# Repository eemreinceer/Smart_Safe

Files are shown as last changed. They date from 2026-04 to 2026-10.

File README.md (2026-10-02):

# SmartSafe

ESP32-CAM based RFID access-control and IoT safe prototype.

SmartSafe combines embedded firmware, a physical RFID authorization path, a solenoid-lock driver, event capture, Firebase Realtime Database synchronization, a web dashboard, KiCad PCB sources and Fusion 360 mechanical files.

## What this project demonstrates

- C++ firmware on ESP32-CAM with FreeRTOS tasks and a non-blocking state-machine design.
- Local RFID allowlist authorization using an RC522 reader.
- Fail-closed handling for missing credentials, missing TLS CA data and unprovisioned OTA authentication.
- Solenoid/MOSFET lock-control path with explicit actuator-command state.
- Firebase RTDB event synchronization with an offline queue.
- Append-only event logging and role-separated database rules for device/admin/operator access.
- PlatformIO build and mock-test workflow with GitHub Actions checks.
- KiCad schematic/PCB sources and Fusion 360 enclosure/mechanical sources.

## Architecture

~~~text
RFID allowlist
      |
      v
ESP32-CAM firmware ---> MOSFET / solenoid lock
      |                         |
      |                         +--> commanded lock state
      v
Firebase RTDB <--------- device status and audit events
      ^
      |
Authorized dashboard ---> alarm command request
~~~

The physical RFID decision is local to the device. The cloud and web dashboard do not directly unlock the safe.

## Repository map

- FIRMWARE/Platform.IO/ - ESP32-CAM firmware, mocks and PlatformIO configuration
- FIRMWARE/WEB/akilli-kasa-dashboard/ - dashboard, Firebase config template and RTDB rules
- PCB/ - KiCad schematic and PCB sources
- 3D/ - Fusion 360 source files
- docs/ - physical bring-up and acceptance checklist
- SECURITY.md - security assumptions and reporting guidance

## Local configuration

Secrets are intentionally excluded from Git. Copy the templates locally:

~~~bash
cd FIRMWARE/Platform.IO
cp include/secrets.example.h include/secrets.h

cd ../WEB/akilli-kasa-dashboard/web
cp firebase-config.example.js firebase-config.js
~~~

Do not commit Wi-Fi credentials, Firebase service-account keys, device passwords, OTA secrets, tokens or personal event images. Use separate Firebase identities for the device and dashboard, and deploy the RTDB rules before connecting a real device.

## Build and test

~~~bash
cd FIRMWARE/Platform.IO
pio run -e esp32cam
pio run -e esp32cam-hardware
pio run -e esp32cam-production
./wokwi_test.sh
~~~

The Wokwi/mock path checks firmware behavior and RFID flows; it is not proof of physical lock safety, cloud availability or hardware electrical correctness. Follow the physical bring-up checklist before energizing a real actuator.

## Security boundaries

- RC522 UID matching is not cryptographic authentication and cards can be cloned.
- is_locked represents the commanded actuator state because the prototype has no physical lock-position sensor.
- A solenoid must use an appropriate external supply, common ground and flyback protection.
- ESP32-CAM and RC522 logic are 3.3 V; signal levels and MOSFET gate drive must be verified against the relevant datasheets.
- This is a prototype and must not be treated as the sole security layer for valuable assets.

## Project scope

This is a personal engineering and learning project. It includes AI-assisted development in parts; the repository documents the implemented architecture, security decisions, test paths and limitations rather than claiming production readiness.

## License

No LICENSE file has been added yet. Reuse and redistribution should not be assumed until a license is explicitly added.

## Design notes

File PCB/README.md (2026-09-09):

# PCB kaynakları

`akilli_guvenlik_kasasi/` altındaki KiCad proje, şema ve PCB dosyaları tasarım
kaynağıdır.

Repository'deki eski Gerber, drill, zip ve schematic PDF dosyaları güncel RFID +
MOSFET mimarisini temsil etmedikleri için kaldırılmıştır. PCB tasarımı
tamamlanıp ERC/DRC kontrolleri geçmeden bu repository'den üretim dosyası
gönderilmemelidir.

Yeni üretim paketi oluşturulurken en az şu dosyalar aynı KiCad revizyonundan
yeniden üretilmelidir:

- Copper, solder mask ve silkscreen Gerber katmanları
- Edge cuts
- PTH ve NPTH drill dosyaları
- Gerber job dosyası
- Assembly/BOM dokümanları
- Görsel kontrol için schematic PDF

KiCad'in kullanıcıya ve yerel pencere durumuna özel `*.kicad_prl` dosyaları
takip edilmez.

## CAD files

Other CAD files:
3D/DFPLAYER.f3d
3D/ESP-32_CAM.f3d
3D/LM2596 VOLTAGE REGULATOR.f3d
3D/PCB.f3z
3D/SOLENOID LOCK.f3d
3D/akilli_guvenlik_kasasi_pcb_v1.f3z

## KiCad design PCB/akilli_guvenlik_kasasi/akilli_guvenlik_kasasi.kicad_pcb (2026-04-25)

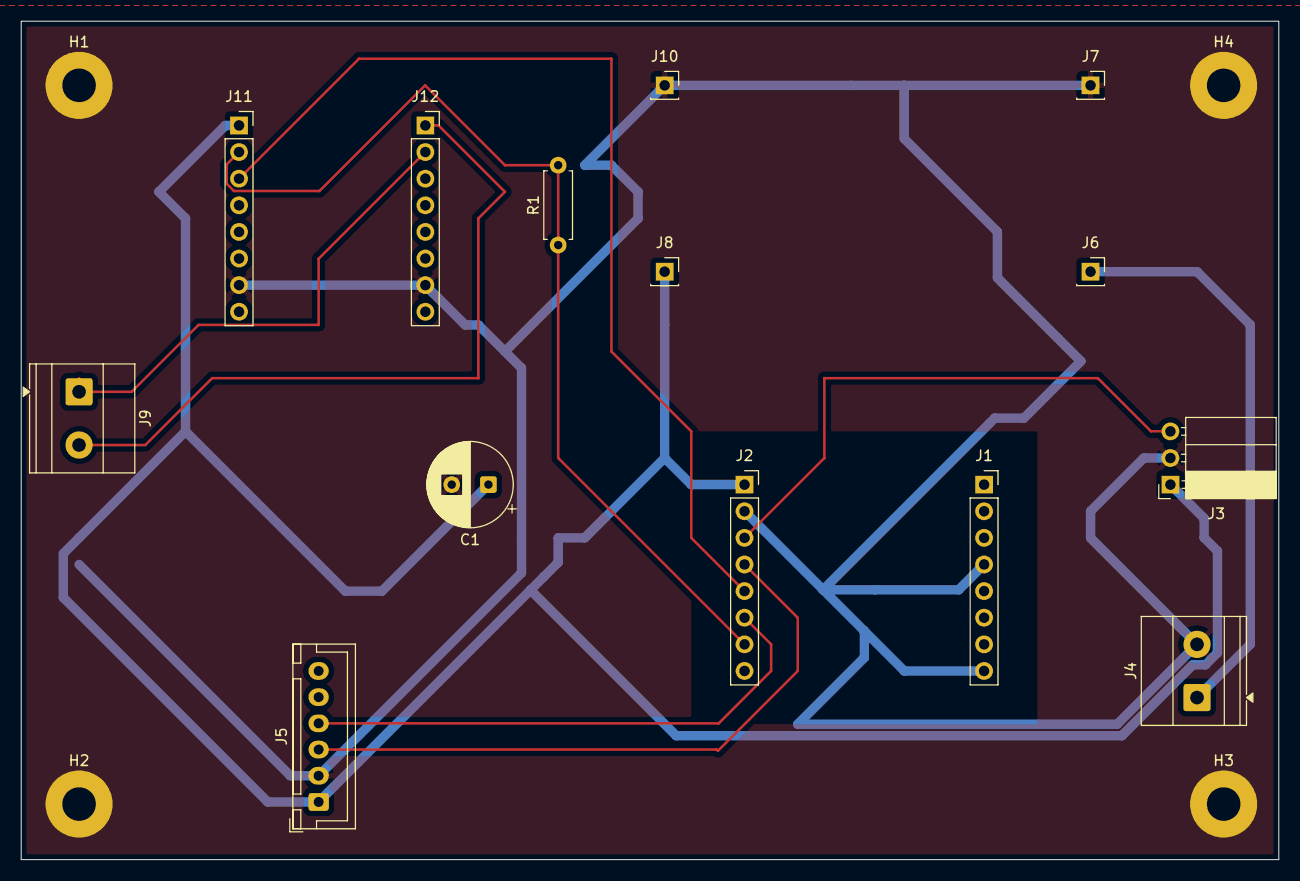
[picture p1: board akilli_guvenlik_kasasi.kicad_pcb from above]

Board: 2 copper layers, 120.0 x 80.0 mm, 18 parts (0 on the bottom side), 10 nets.

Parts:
C1: 470uf; CP_Radial_D8.0mm_P3.50mm
H1, H2, H3, H4: MountingHole_Pad; MountingHole_3.2mm_M3_Pad
J1: ESP-32_SAG; PinSocket_1x08_P2.54mm_Vertical
J2: ESP-32_SOL; PinSocket_1x08_P2.54mm_Vertical
J3: ROLE_MODULU; PinSocket_1x03_P2.54mm_Horizontal
J4: GUC_GİRİSİ; TerminalBlock_Phoenix_MKDS-1,5-2-5.08_1x02_P5.08mm_Horizont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
J5: R503 PARMAK İZİ; JST_XH_B6B-XH-A_1x06_P2.50mm_Vertical
J6: 12V_IN; PinSocket_1x01_P2.54mm_Vertical
J7: 12V_GND; PinSocket_1x01_P2.54mm_Vertical
J8: 5V_IN; PinSocket_1x01_P2.54mm_Vertical
J9: J_HOPARLOR; TerminalBlock_Phoenix_MKDS-1,5-2-5.08_1x02_P5.08mm_Horizont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
J10: 5V_GND; PinSocket_1x01_P2.54mm_Vertical
J11: DF_SOL; PinSocket_1x08_P2.54mm_Vertical
J12: DF_SAG; PinSocket_1x08_P2.54mm_Vertical
R1: 1K; R_Axial_DIN0207_L6.3mm_D2.5mm_P7.62mm_Horizontal

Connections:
/+5V: C1.1, J2.1, J3.1, J5.1, J8.1, J11.1
/+12V: J4.1, J6.1
/HOPARLOR_A: J9.2, J12.1
/HOPARLOR_B: J9.1, J12.2
/KILIT_TETIK: J2.3, J3.3
/MP3_RX: J2.5, J11.3
/MP3_TX: J2.7, J11.2, R1.1, R1.2
/PARMAK_RX: J2.4, J5.3
/PARMAK_TX: J2.6, J5.4
GND: C1.2, H1.1, H2.1, H3.1, H4.1, J1.4, J1.8, J2.2, J3.2, J4.2, J5.2, J7.1, J10.1, J11.7, J12.7

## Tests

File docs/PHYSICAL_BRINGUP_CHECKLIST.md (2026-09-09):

# SmartSafe Physical Bring-Up Checklist

Bu kontrol listesi tamamlanmadan `esp32cam-production` firmware'i fiziksel sisteme
yüklenmemeli ve solenoid beslemesi uygulanmamalıdır. Firmware build başarısı,
elektriksel güvenlik veya mekanik kilit geri bildirimi kanıtı değildir.

## 1. Enerji vermeden önce — NO-GO kapısı

- [ ] Güncel şema, PCB ve Gerber aynı revizyonu temsil ediyor.
- [ ] ESP32-CAM, RC522, DFPlayer ve MOSFET pinleri gerçek kablolamayla eşleşiyor.
- [ ] GPIO2, GPIO12 ve GPIO15 strapping-pin etkileri harici devreyle birlikte kontrol edildi.
- [ ] RC522 beslemesi ve tüm SPI sinyalleri 3.3 V seviyesinde.
- [ ] Solenoid akımı ESP32/logic regülatöründen geçmiyor.
- [ ] Logic ve actuator GND ilişkisi şemaya uygun; yük akımı logic ground yolundan geçmiyor.
- [ ] MOSFET, 3.3 V gate geriliminde ölçülen solenoid akımına uygun.
- [ ] Flyback diyot yönü ve akım kapasitesi doğrulandı.
- [ ] Besleme polaritesi, sigorta ve erişilebilir power disconnect mevcut.
- [ ] 12 V–GND, 5 V–GND ve 3.3 V–GND arasında kısa devre yok.
- [ ] Açıkta iletken, gevşek konnektör veya yetersiz strain relief yok.

Bu bölümde tek bir madde bile belirsizse durum **NO-GO**'dur.

## 2. Kademeli ilk enerji verme

- [ ] Akım limitli bench supply kullanıldı; limit beklenen idle akıma yakın başlatıldı.
- [ ] Önce yalnızca power source/regülatör, yüksüz test edildi.
- [ ] Yalnızca ESP32-CAM enerjilendirildi ve kararlı boot doğrulandı.
- [ ] RC522 tek başına eklendi ve tanımlı/tanımsız kart okuması doğrulandı.
- [ ] Kamera eklendi; capture sırasında brownout/reset olmadığı doğrulandı.
- [ ] DFPlayer eklendi; boot strapping ve UART seviyesi kontrol edildi.
- [ ] Solenoid beslemesi kapalıyken MOSFET gate komutu ölçüldü.
- [ ] Solenoid mekanik olarak yüksüz ve kısa süreli olarak ayrı test edildi.
- [ ] En son tüm sistem, akım ve voltage sag izlenerek birleştirildi.

## 3. Firmware ve security kabulü

- [ ] `include/secrets.h` Git tarafından izlenmiyor.
- [ ] En az `AUTHORIZED_UID_1` gerçek karta ait ve UID formatı doğrulandı.
- [ ] `pio run -e esp32cam-production` başarılı.
- [ ] Tanımlı kart kilidi bir kez ve 3 saniye açıyor.
- [ ] Tanımsız kart kilidi açmıyor ve audit event oluşturuyor.
- [ ] Üç hatalı deneme lockdown ve alarm oluşturuyor.
- [ ] Lockdown sonunda RFID taraması kontrollü olarak geri geliyor.
- [ ] Cloud/web panelinden kilit açma yolu bulunmuyor.
- [ ] Wi-Fi ve Firebase kapalıyken tanımlı RFID kart yerel olarak çalışıyor.
- [ ] Wi-Fi geri geldiğinde offline log ve NTP davranışı doğrulanıyor.
- [ ] Reset/brownout sonrası actuator varsayılan olarak kilitli kalıyor.
- [ ] Firebase device hesabında yalnızca `device_id: safe_001` claim'i var.
- [ ] Dashboard hesabı ile device hesabı birbirinden ayrı.

## 4. Ölçüm kaydı

| Aşama | Vin | 5 V | 3.3 V | Idle akım | Peak akım | En düşük gerilim | Regülatör/MOSFET sıcaklığı | Sonuç |
|---|---:|---:|---:|---:|---:|---:|---:|---|
| Regülatör yüksüz | | | | | | | | |
| ESP32-CAM boot | | | | | | | | |
| RC522 okuma | | | | | | | | |
| Kamera capture | | | | | | | | |
| DFPlayer alarm | | | | | | | | |
| Solenoid tek başına | | | | | | | | |
| Entegre sistem | | | | | | | | |

Kısa transient, PWM/gate dalga şekli ve inrush için multimetre tek başına yeterli
değildir; oscilloscope veya logic analyzer kaydı alınmalıdır.

## Kabul durumu

- **SAFE TO PROCEED:** Tüm maddeler tamamlandı, değerler limit içinde ve test kanıtı kaydedildi.
- **BLOCKED:** Kısa devre, ters polarite, boot instability, brownout, aşırı akım/ısı veya fail-open davranış var.
- **UNKNOWN:** Ölçülmemiş her elektriksel veya mekanik davranış.

Mevcut repository durumu, PCB ve fiziksel ölçümler tamamlanana kadar
**software-verified / physical NO-GO** olarak kabul edilir.

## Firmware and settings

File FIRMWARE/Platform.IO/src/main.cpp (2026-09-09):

#include <Arduino.h>

#include "config.h"
#include "events.h"
#include "wifi_manager.h"
#include "security_manager.h"
#include "rfid.h"
#include "camera.h"
#include "lock.h"
#include "alarm.h"
#include "firebase.h"
#include "ota.h"
#include "eventlogger.h"
#include "offlinequeue.h"
#include "systemstate.h"

#include "esp_task_wdt.h"

// ─────────────────────────────────────────────
//  Forward Declarations
// ─────────────────────────────────────────────
void taskRFID    (void* pv);
void taskSecurity(void* pv);
void taskCloud   (void* pv);
void taskWifi    (void* pv);
void taskSystem  (void* pv);


// ══════════════════════════════════════════════
//  TASK 1 — RFID Okuyucu  |  Core 1  |  Prio 2
// ══════════════════════════════════════════════
void taskRFID(void* pv)
{
    esp_task_wdt_add(NULL);
    while (true)
    {
        if (securityIsLockedDown() ||
            getState() == STATE_LOCKDOWN ||
            getState() == STATE_ALARM)
        {
            esp_task_wdt_reset();
            vTaskDelay(pdMS_TO_TICKS(1000));
            continue;
        }

        int cardID = readRFID();

        SafeEvent ev;
        memset(&ev, 0, sizeof(ev));

        if (cardID > 0)
        {
            ev.type = EVENT_AUTHORIZED;
            snprintf(ev.id, sizeof(ev.id), "KART-%d", cardID);
            setState(STATE_AUTHORIZED);
            xQueueSend(eventQueue, &ev, portMAX_DELAY);
        }
        else if (cardID == -2)
        {
            ev.type = EVENT_UNAUTHORIZED;
            snprintf(ev.id, sizeof(ev.id), "UNKNOWN");
            setState(STATE_UNAUTHORIZED);
            xQueueSend(eventQueue, &ev, portMAX_DELAY);
        }
        else
        {
            if (getState() != STATE_LOCKDOWN &&
                getState() != STATE_ALARM)
                setState(STATE_IDLE);
        }

        vTaskDelay(pdMS_TO_TICKS(200));
        esp_task_wdt_reset();
    }
}


// ══════════════════════════════════════════════
//  TASK 2 — Security  |  Core 1  |  Prio 2
// ══════════════════════════════════════════════
void taskSecurity(void* pv)
{
    esp_task_wdt_add(NULL);
    SafeEvent ev;

    while (true)
    {
        if (xQueueReceive(eventQueue, &ev, pdMS_TO_TICKS(8000)) != pdTRUE)
        {
            esp_task_wdt_reset();
            continue;
        }

        securityHandleEvent(ev);
        esp_task_wdt_reset();
    }
}


// ══════════════════════════════════════════════
//  TASK 3 — Cloud  |  Core 0  |  Prio 1
// ══════════════════════════════════════════════
void taskCloud(void* pv)
{
    esp_task_wdt_add(NULL);
    unsigned int counter = 0;
    bool lastPublishedLockState = isSafeLocked();

    while (true)
    {
        handleOTA();

        const bool lockState = isSafeLocked();
        if (lockState != lastPublishedLockState && wifiIsConnected())
        {
            if (updateLockState(lockState))
                lastPublishedLockState = lockState;
        }

        if (counter % 5 == 0 && wifiIsConnected())
        {
            if (!firebaseIsReady() && firebaseIsConfigured())
                initFirebase();

            trySyncOfflineLogs();

            bool alarmTrigger = false;
            if (checkRemoteCommands(alarmTrigger))
            {
                if (alarmTrigger)
                {
                    Serial.println("[CLOUD] Uzaktan alarm!");
                    SafeEvent rem;
                    memset(&rem, 0, sizeof(rem));
                    rem.type = EVENT_REMOTE_ALARM;
                    if (xQueueSend(eventQueue, &rem, 0) != pdTRUE)
                        Serial.println("[CLOUD] Security queue dolu; alarm reddedildi");
                }
            }
        }

        if (counter % 60 == 0 && wifiIsConnected())
            updateDeviceStatus();

        counter++;
        vTaskDelay(pdMS_TO_TICKS(1000));
        esp_task_wdt_reset();
    }
}


// ══════════════════════════════════════════════
//  TASK 4 — WiFi Monitor  |  Core 0  |  Prio 1
// ══════════════════════════════════════════════
void taskWifi(void* pv)
{
    esp_task_wdt_add(NULL);
    while (true)
    {
        wifiReconnect();
        esp_task_wdt_reset();
        vTaskDelay(pdMS_TO_TICKS(5000));
    }
}


// ══════════════════════════════════════════════
//  TASK 5 — System Monitor  |  Core 0  |  Prio 1
// ══════════════════════════════════════════════
void taskSystem(void* pv)
{
    esp_task_wdt_add(NULL);
    unsigned long lastReportAt = 0;
    while (true)
    {
        securityCheckExpiry();
        serviceLock();

        if (millis() - lastReportAt >= 5000)
        {
            lastReportAt = millis();
            Serial.printf("[SYS] Heap: %u | State: %s | WiFi: %s\n",
                          ESP.getFreeHeap(),
                          getStateName(getState()),
                          wifiIsConnected() ? "OK" : "DOWN");

            const unsigned long remaining = securityGetLockRemainingMs();
            if (remaining > 0)
                Serial.printf("[SYS] Lockdown: %lu ms kaldi\n", remaining);
        }

        vTaskDelay(pdMS_TO_TICKS(50));
        esp_task_wdt_reset();
    }
}


// ══════════════════════════════════════════════
//  SETUP
// ══════════════════════════════════════════════
void setup()
{
    Serial.begin(115200);
    delay(2000);
    Serial.println("\n========================================");
    Serial.println("[SETUP] Akilli Guvenlik Kasasi basliyor");
    Serial.println("========================================");

    #if SIMULATION_MODE
    Serial.println("[SETUP] SIMULASYON MODU");
    #endif
    #if RFID_MOCK
    Serial.println("[SETUP] RFID MOCK - Komut: RFID:AABBCCDD");
    #endif

    // ── Donanım ──────────────────────────────
    initLogger();
    initOfflineQueue();
    initRFID();
    initCamera();
    initLock();
    initAlarm();

    // ── Ağ (WiFi + NTP) ──────────────────────
    wifiInit();

    // ── Bulut ────────────────────────────────
    initFirebase();
    initOTA();

    // ── Güvenlik state makinesi ───────────────
    securityInit();
    setState(STATE_IDLE);

    // ── WDT: 30 sn (SSL 8 sn + işlem payı) ──
    esp_task_wdt_init(30, true);
    esp_task_wdt_add(NULL);

    if (eventQueue == NULL)
    {
        Serial.println("[SETUP] eventQueue NULL! Sistem durdu.");
        while (true);
    }

    // ── Task'lar ─────────────────────────────
    bool tasksOk = true;
    tasksOk = xTaskCreatePinnedToCore(taskRFID,     "rfid",     4096,  NULL, 2, NULL, 1) == pdPASS && tasksOk;
    tasksOk = xTaskCreatePinnedToCore(taskSecurity, "security", 12288, NULL, 2, NULL, 1) == pdPASS && tasksOk;
    tasksOk = xTaskCreatePinnedToCore(taskCloud,    "cloud",    12288, NULL, 1, NULL, 0) == pdPASS && tasksOk;
    tasksOk = xTaskCreatePinnedToCore(taskWifi,     "wifi",     4096,  NULL, 1, NULL, 0) == pdPASS && tasksOk;
    tasksOk = xTaskCreatePinnedToCore(taskSystem,   "system",   2048,  NULL, 1, NULL, 0) == pdPASS && tasksOk;

    if (!tasksOk)
    {
        lockSafe();
        Serial.println("[SETUP] Task olusturma basarisiz; kilit safe state'te.");
        esp_restart();
    }

    Serial.println("[SETUP] SMART SAFE READY\n");
}


// ══════════════════════════════════════════════
//  LOOP
// ══════════════════════════════════════════════
void loop()
{
    esp_task_wdt_reset();
    vTaskDelay(pdMS_TO_TICKS(1000));
}

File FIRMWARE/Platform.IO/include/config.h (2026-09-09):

#ifndef CONFIG_H
#define CONFIG_H

// ══════════════════════════════════════════════
//  SİMÜLASYON MODU
//  true  → Donanım yok, Serial ile test
//  false → Gerçek sensörler bağlı
// ══════════════════════════════════════════════
#ifndef SIMULATION_MODE
#define SIMULATION_MODE 1
#endif
#ifndef RFID_MOCK
#define RFID_MOCK SIMULATION_MODE
#endif
#ifndef REQUIRE_PROVISIONING
#define REQUIRE_PROVISIONING 0
#endif

// ══════════════════════════════════════════════
//  WiFi Ayarları
// ══════════════════════════════════════════════
// Wokwi simulator için Wokwi-GUEST kullanın (şifresiz, internet açık).
// Gerçek donanımda kendi WiFi'nızı yazın.
#if __has_include("secrets.h")
#include "secrets.h"
#else
#define WIFI_SSID                 "Wokwi-GUEST"
#define WIFI_PASSWORD             ""
#define FIREBASE_API_KEY          ""
#define FIREBASE_DATABASE_URL     ""
#define FIREBASE_AUTH_EMAIL       ""
#define FIREBASE_AUTH_PASSWORD    ""
#define FIREBASE_ROOT_CA_PEM      ""
#define OTA_PASSWORD_HASH         ""
#if SIMULATION_MODE
#define AUTHORIZED_UID_1          "A1B2C3D4"
#else
#define AUTHORIZED_UID_1          ""
#endif
#define AUTHORIZED_UID_2          ""
#define AUTHORIZED_UID_3          ""
#endif

// ══════════════════════════════════════════════
//  Firebase Ayarları
// ══════════════════════════════════════════════
#define API_KEY            FIREBASE_API_KEY
#define DATABASE_URL       FIREBASE_DATABASE_URL
#define AUTO_INIT_FIREBASE 1

// ══════════════════════════════════════════════
//  NTP Ayarları
// ══════════════════════════════════════════════
#define NTP_SERVER      "pool.ntp.org"
#define NTP_GMT_OFFSET  10800
#define NTP_DAYLIGHT    0

// ══════════════════════════════════════════════
//  Cihaz Bilgileri
// ══════════════════════════════════════════════
#define DEVICE_ID       "safe_001"
#define FIRMWARE_VER    "1.0.0"

// ══════════════════════════════════════════════
//  Sistem Ayarları
// ══════════════════════════════════════════════
#define LOCKDOWN_DURATION_MS  30000
#define ALARM_DURATION_MS     10000
#define MAX_FAIL_ATTEMPTS     3
#define LOCK_OPEN_DURATION_MS 3000

// ══════════════════════════════════════════════
//  Yetkili RFID Kart UID'leri
//  Format: 4 byte hex, büyük harf, örn: "A1B2C3D4"
//  Kartını okumak için SIMULATION_MODE=false yap,
//  Serial Monitor'da UID otomatik yazdırılır.
// ══════════════════════════════════════════════
#define AUTHORIZED_UID_COUNT 3
static const char* AUTHORIZED_UIDS[AUTHORIZED_UID_COUNT] = {
    AUTHORIZED_UID_1,
    AUTHORIZED_UID_2,
    AUTHORIZED_UID_3
};

#if REQUIRE_PROVISIONING
static_assert(sizeof(AUTHORIZED_UID_1) > 1,
              "Production firmware requires at least AUTHORIZED_UID_1 in secrets.h");
#endif

// ══════════════════════════════════════════════
//  Pin Tanımları (GERÇEK DONANIM)
//  ESP32-CAM AI Thinker uyumlu
// ══════════════════════════════════════════════
#if !SIMULATION_MODE

    // Solenoid kilit (IRLZ44N MOSFET Gate)
    #define RELAY_PIN        2

    // RC522 RFID — HSPI (özel pin mapping)
    #define RFID_SS_PIN     15   // SDA/SS
    #define RFID_SCK_PIN    14   // SCK
    #define RFID_MISO_PIN    4   // MISO
    #define RFID_MOSI_PIN   13   // MOSI
    // RST → 3.3V'a sabit bağlı (UNUSED_PIN)

    // DFPlayer Mini — UART (tek yönlü, sadece TX)
    #define DF_TX           12   // ESP32 TX → DFPlayer RX
    // DF_RX bağlı değil, ACK devre dışı

#endif

#endif

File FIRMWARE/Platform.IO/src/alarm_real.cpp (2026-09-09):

#include "config.h"

#if !SIMULATION_MODE

#include <Arduino.h>
#include "alarm.h"
#include <DFRobotDFPlayerMini.h>
#include <HardwareSerial.h>

// RX=-1 → bağlı değil, sadece TX kullanılıyor
HardwareSerial dfSerial(1);
DFRobotDFPlayerMini dfplayer;

void initAlarm()
{
    // RX pini -1 → bağlı değil
    dfSerial.begin(9600, SERIAL_8N1, -1, DF_TX);

    // ACK=false → DFPlayer'dan yanıt bekleme (RX hattı olmadığı için)
    if (!dfplayer.begin(dfSerial, false))
        Serial.println("[ALARM] ❌ DFPlayer başlatılamadı");
    else
    {
        dfplayer.volume(25);   // 0-30 arası ses seviyesi
        Serial.println("[ALARM] ✅ DFPlayer hazır");
    }
}

void triggerAlarm()
{
    Serial.println("[ALARM] 🚨 Alarm tetiklendi!");
    dfplayer.play(1);   // SD karttaki 001.mp3 dosyasını çal
}

void stopAlarm()
{
    dfplayer.stop();
    Serial.println("[ALARM] Alarm durduruldu");
}

#endif

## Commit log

2026-04-17 SmartSafe
    AI-Powered Smart Safe System with Real-Time Face Recognition and Web Dashboard.
    [DFPLAYER.f3d, FINGERPRINT.f3d, LM2596 VOLTAGE REGULATOR.f3d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]
2026-04-25 Initial commit: Akıllı Güvenlik Kasası (Smart Safe) v1.0.0
    - ESP32-CAM firmware (PlatformIO/Arduino) — RFID, solenoid lock, Firebase, OTA, DFPlayer
    - React web dashboard — Firebase Realtime Database, remote unlock
    - Python AI server — DeepFace/ArcFace yüz tanıma, Firebase Admin SDK
    - KiCad PCB tasarımı + Gerber dosyaları
    - Wokwi simülasyon devresi (diagram.json) + entegrasyon test scripti
    - config.h.example ile güvenli credential yönetimi
    [akilli_guvenlik_kasasi-B_Cu.gbr, akilli_guvenlik_kasasi-B_Mask.gbr, akilli_guvenlik_kasasi-B_Paste.gbr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]
2026-04-25 Remove python folder — not part of project scope
2026-04-25 Clean up old/duplicate folder structure
    Remove: src/, PCB/ (uppercase), ReadME.md, root requirements.txt,
    web/script.js, web/style.css — replaced by new organized layout.
    Keep: 3D/ models, firmware/, web/src/, pcb/ (lowercase gerber+kicad).
    [akilli_guvenlik_kasasi-B_Cu.gbr, akilli_guvenlik_kasasi-B_Mask.gbr, akilli_guvenlik_kasasi-B_Paste.gbr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]
2026-05-18 refactor: proje yapısı yeniden düzenlendi, web dashboard güncellendi, .gitignore eklendi
    [akilli_guvenlik_kasasi-B_Cu.gbr, akilli_guvenlik_kasasi-B_Mask.gbr, akilli_guvenlik_kasasi-B_Paste.gbr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]
2026-09-09 Clean stale artifacts and local files
    [FINGERPRINT.f3d, RELAY MODULE.f3d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]
